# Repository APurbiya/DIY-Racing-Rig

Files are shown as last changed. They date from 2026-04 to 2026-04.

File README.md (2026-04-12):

 

<p align="center">
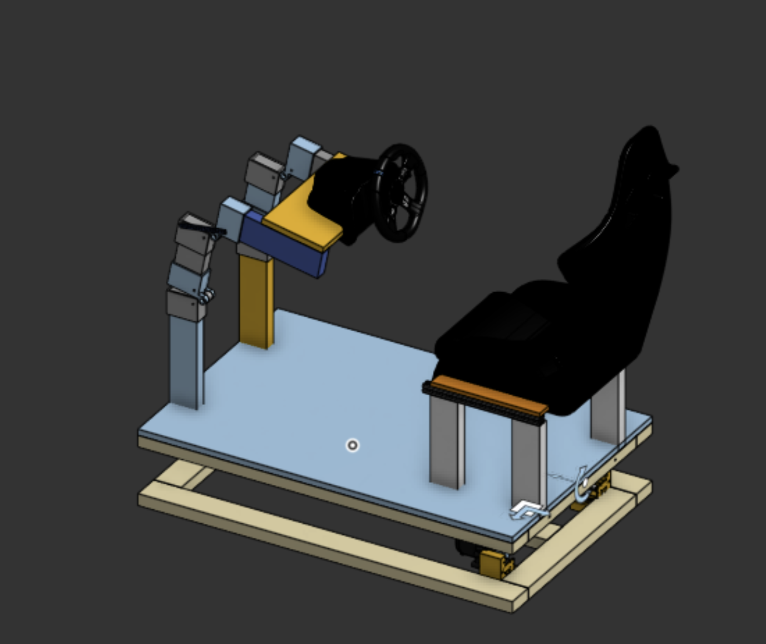
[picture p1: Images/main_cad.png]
DIY-Racing-Rig
  
</p>

# DIY-Racing-Rig
An open-source, 2-Degree-of-Freedom (2DOF) motion racing simulator designed for high immersion and DIY accessibility. This project utilizes a robust timber frame, high-torque DC gear motors, and magnetic encoders to translate in-game telemetry into real-time physical pitch and roll.

We wanted to make this project as it gives us not only experience in building a cool project, but also lets us have fun with the project, by playing on it once it is done. 

By Arnav Purbiya and Sai Avula

# Table of Contents

- [System Overview](#system-overview)
- [CAD](#cad)
- [3D Printing Guide](#3d-printing-guide)
- [Assembly Guide](#assembly-guide)
- [Electronics](#electronics)
- [Firmware](#firmware)
- [BOM](#bom)

# System Overview

The DIY-Racing-Rig is a motion-actuated platform designed to bridge the gap between virtual racing and physical reality. By translating in-game telemetry into physical movement, the rig simulates the G-forces, weight shifts, and road textures experienced during high-performance driving.

### How It Works
The system operates as a **2-Degree-of-Freedom (2DOF)** motion platform, focusing on the two most critical axes for racing immersion:
* **Pitch:** Simulates the longitudinal forces of acceleration (leaning back) and braking (leaning forward).
* **Roll:** Simulates the lateral forces of cornering and weight transfer through turns.

### Mechanical Architecture
* **The Fulcrum:** A heavy-duty, 3D-printed **Universal Joint (U-Joint)** serves as the mechanical heart of the rig. It supports the full weight of the upper chassis and driver while allowing for fluid movement across both axes.
* **Actuation:** High-torque 24V 250W geared DC motors drive the platform via a physical linkage system. These motors are capable of rapid transitions to mimic sudden weight shifts or bumps in the road.

### Electronic Control & Feedback
To ensure precision and eliminate "drift," the rig utilizes a **Closed-Loop Feedback System**:
1.  **Telemetry Data:** Software (SimTools) extracts live physics data from the game and sends it to an **Arduino Uno R3**.
2.  **Logic:** The Arduino calculates the required position for each motor.
3.  **Position Sensing:** **AS5600 Magnetic Encoders** mounted to the motors provide real-time angular feedback, allowing the Arduino to verify the rig's exact orientation.
4.  **Power Delivery:** High-current **BTS7960 Motor Drivers** translate the logic signals into raw power, moving the motors to the target position with high torque and low latency.

### Design Goals
* **Accessibility:** Built primarily from standard 2x4 timber and 3D-printed components to keep costs low.
* **Durability:** Strategic use of PETG in high-stress areas (U-Joint and Control Arms) ensures long-term structural integrity.
* **Immersive Precision:** The combination of 250W motors and magnetic encoders provides a snappy, responsive experience that reacts instantly to in-game events.

# CAD
You can find the cad on onshape, link down bellow
https://cad.onshape.com/documents/b552f3261af86a9135d49db9/w/8cfbd36bcd7ad18b09077ea0/e/34b6498e013fb992d3270d66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

## 3D Printing Guide

For structural components like the U-Joint and Center, **PETG** is preferred for its impact resistance and durability. If substituting with **PLA**, ensure the part is kept away from high-heat environments.

| Part Name | Qty | Material (Rec.) | Infill / Settings | Notes |
| :--- | :---: | :--- | :--- | :--- |
| **Hinge P1** | 4 | PLA | Default | Standard settings. |
| **Hinge P2** | 4 | PLA | Default | Standard settings. |
| **Hinge Strap** | 4 | PLA | Default | Standard settings. |
| **U-Joint Top** | 1 | PETG | 50% | High stress; PLA acceptable at 50%. |
| **U-Joint Bottom** | 1 | PETG | 50% | High stress; PLA acceptable at 50%. |
| **U Joint Center** | 1 | PETG | 50% (4 Walls) | Structural core; use 4 wall loops. |
| **Motor Mounts** | 2 | PLA | 20% | Standard settings. |
| **Motor Control Arms**| 2 | PETG | 80% Gyroid | Use Gyroid infill for maximum rigidity. |

---

## Assembly Guide

### Phase 1: The Cut List
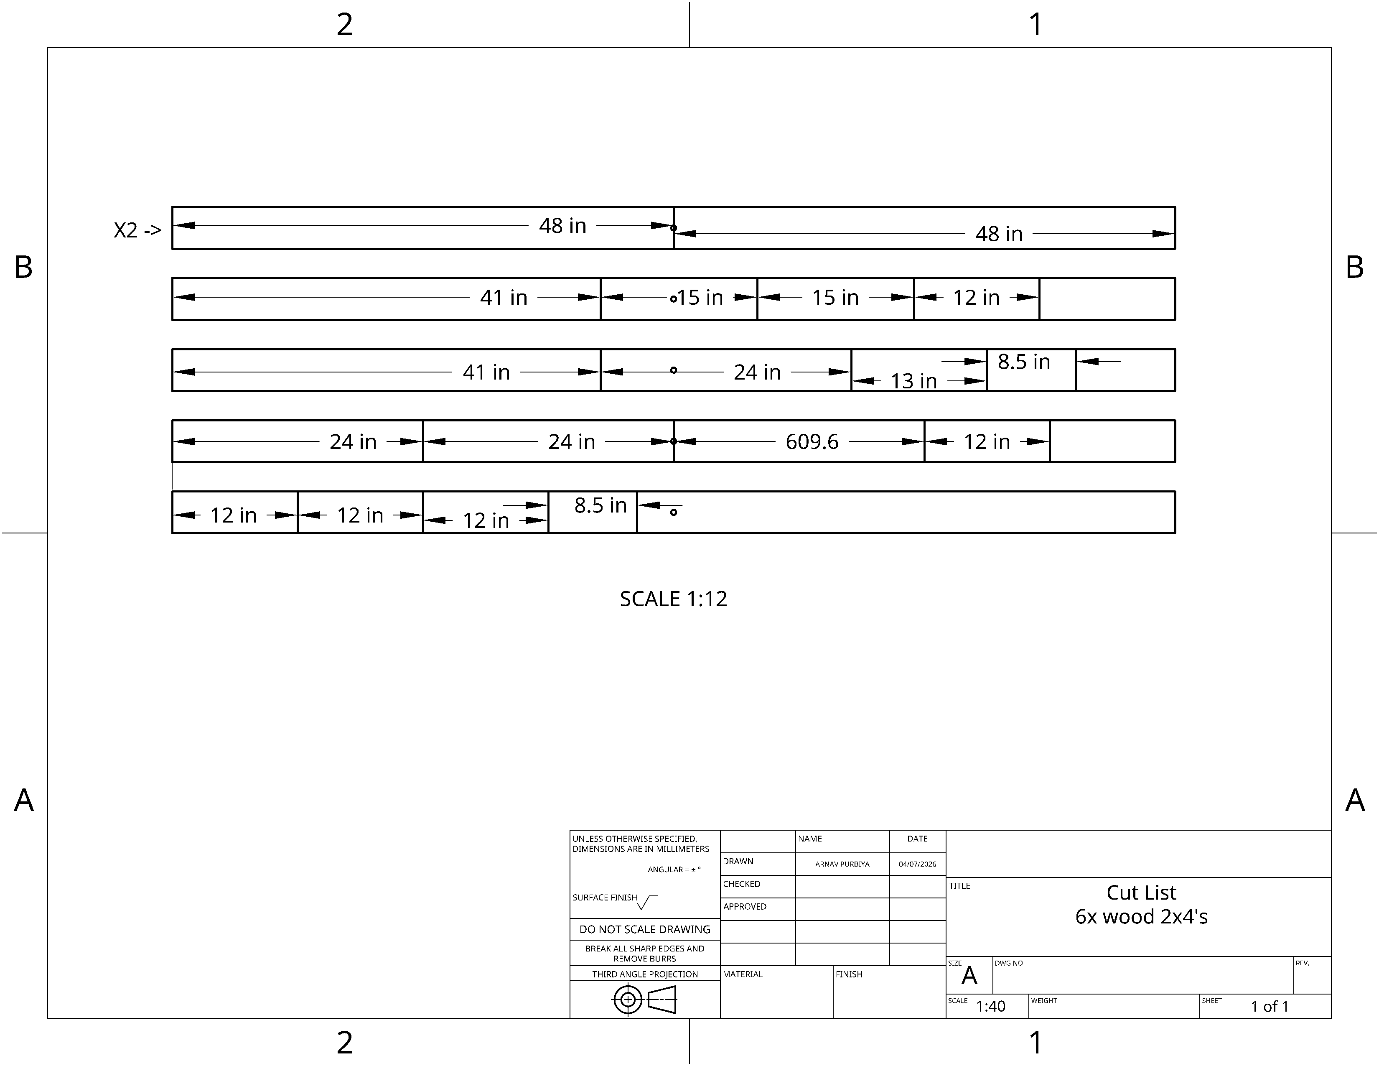
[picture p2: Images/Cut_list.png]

Before beginning assembly, reference the `cut_list.png` diagram. 
* **Stock:** Use (6) standard 8-foot 2x4s.
* **Precision:** The cut list accounts for the saw blade kerf. 
* **Scrap:** Expect a small amount of leftover material at the end of each board.

### Phase 2: Building the Dual Bases
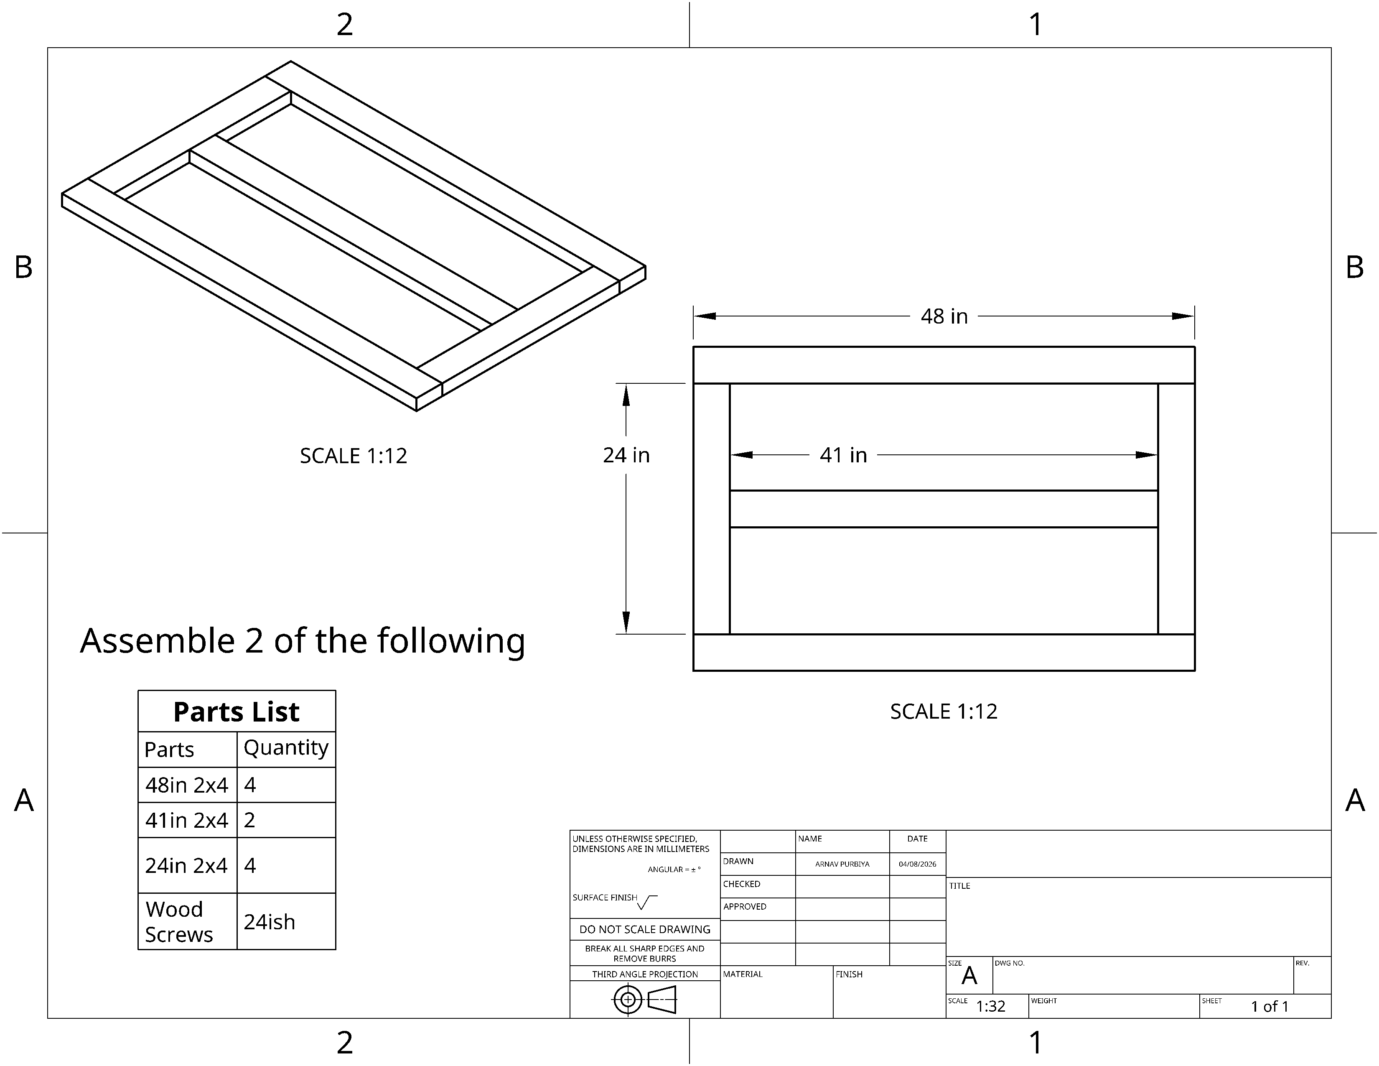
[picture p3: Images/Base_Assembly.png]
Base Assembly

You will need to construct **two identical base units** following the `base_assembly` guide. 
1. Lay out the 2x4 segments as indicated in the assembly diagram.
2. Fasten the joints using wood screws or heavy-duty lag bolts. 
3. **Note:** One base will serve as the ground foundation, while the second will serve as the top platform mounted to the U-Joint.

### Phase 3: The U-Joint & Center Hub
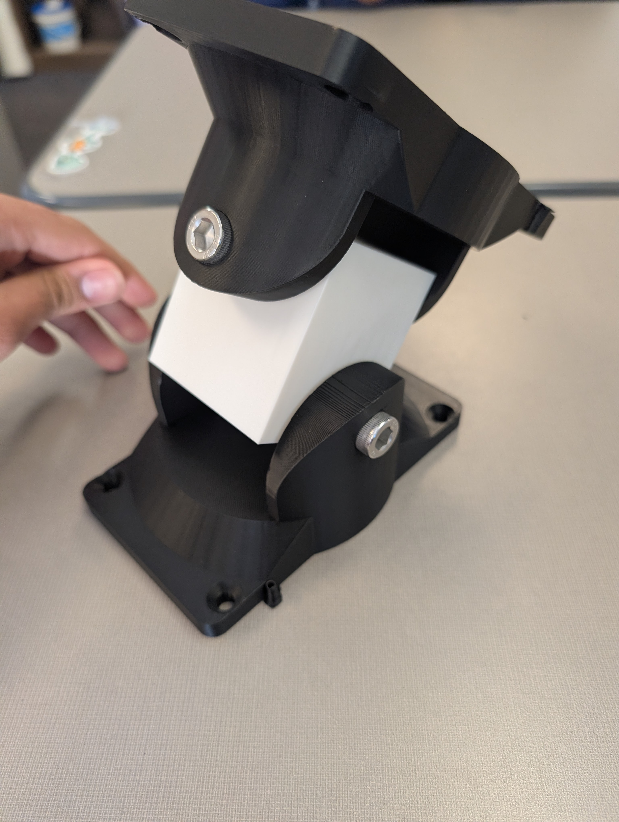
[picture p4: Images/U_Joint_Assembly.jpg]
U_Joint_Assembly

This is the mechanical heart of the build. The U joint is put together with 4 M10 Bolts and Lock Nuts 
1. **Lower Mount:** Attach the **U-Joint Bottom** to the center of the ground base. 
2. **Center Integration:** Insert the **Center Hub** into the U-Joint assembly.
3. **Upper Mount:** Attach the **U-Joint Top** to the 41-inch center 2x4 of the second (top) base.
4. **Final Marriage:** Join the top base assembly to the bottom base assembly via the U-Joint. Ensure all mechanical pivots move freely before tightening fasteners.

### Phase 4: Steering Wheel Stand Assembly
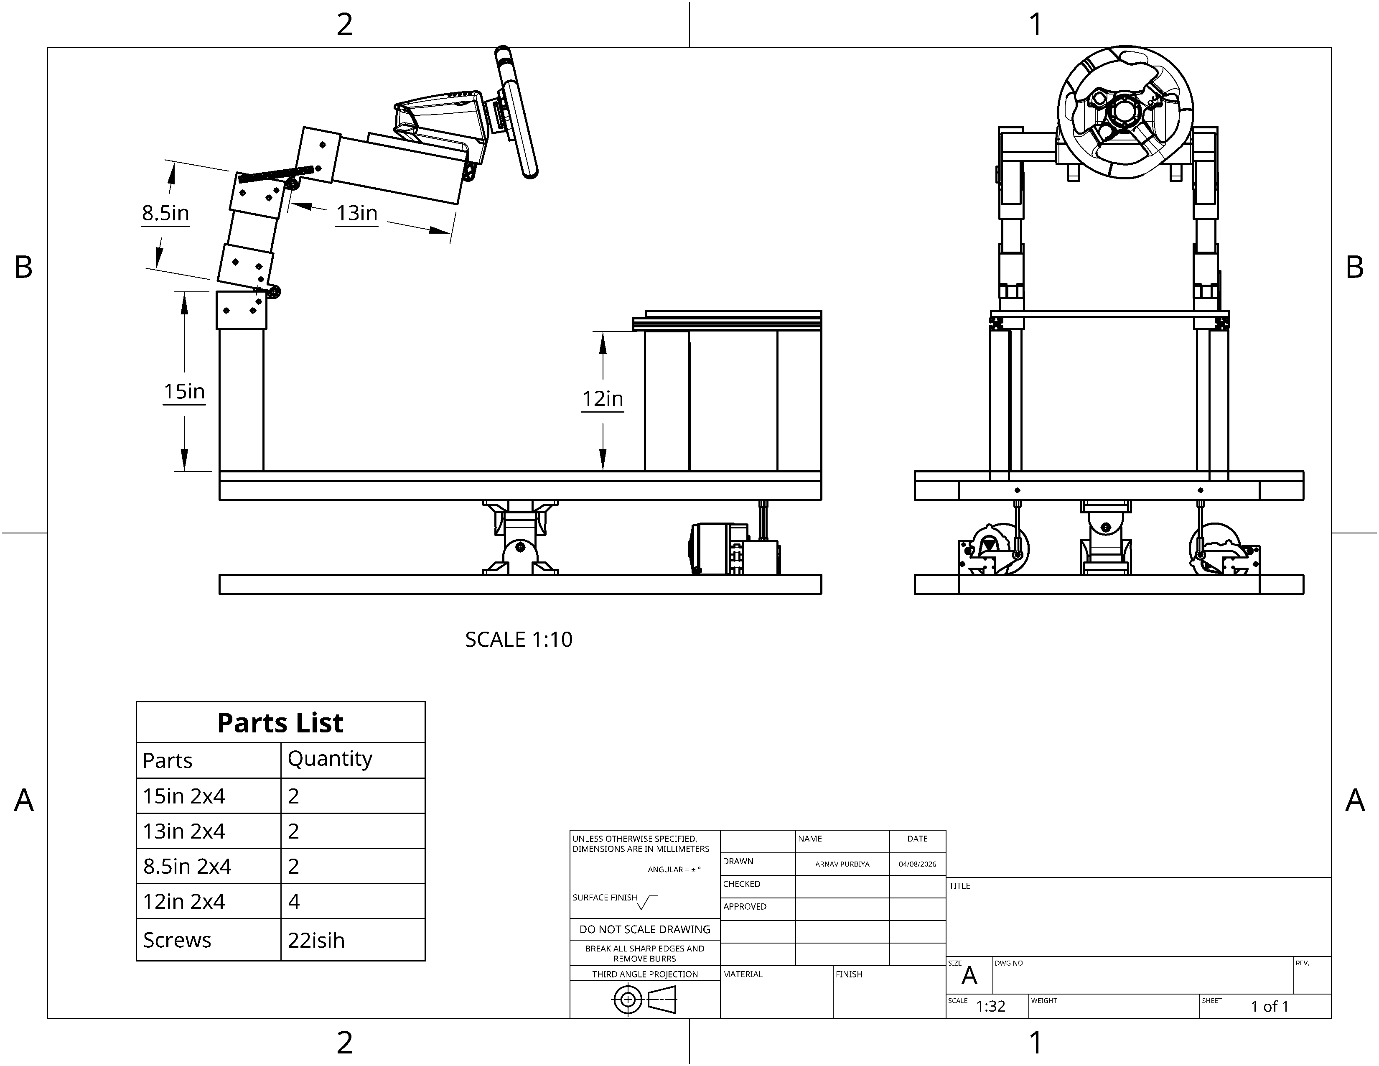
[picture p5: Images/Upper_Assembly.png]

The steering wheel stand is a hinged vertical assembly. Reference the `upper_assembly` diagram for specific orientation.
1. **Hinge Preparation:** Connect **Hinge 1** and **Hinge 2** using an **M10 bolt and nut**. Ensure the hinge is snug but allows for smooth rotation.
2. **Wood Sequence:** Mount the 2x4 segments to the hinges using wood screws. The assembly order from top to bottom is:
    * **15-inch segment** (Top)
    * **8.5-inch segment** (Middle)
    * **13-inch segment** (Bottom)
3. **Orientation:** When mounting, ensure the **hinge pivot point faces the inside** of the assembly to allow for proper folding/adjustment.

### Phase 5: Seat Stand Installation
The seat stand is adjustable based on your specific seating hardware.
1. **Placement:** Take the (4) **12-inch 2x4 segments**.
2. **Mounting:** Screw these into the bottom base assembly. 
3. **Spacing:** Adjust the distance between these segments to match the mounting rails or holes of your specific seat before final fastening.

### Phase 6: Motors and Linkage
1. **Actuation:** Install the **Motor Mounts** to the designated points on the frame. 
2. **Linkage:** Connect the **Motor Control Arms** between the motors and the moving frame. These arms provide the mechanical leverage for the motion system.
3. This is all done with the threaded rods and the bearing rod ends
---

## Electronics
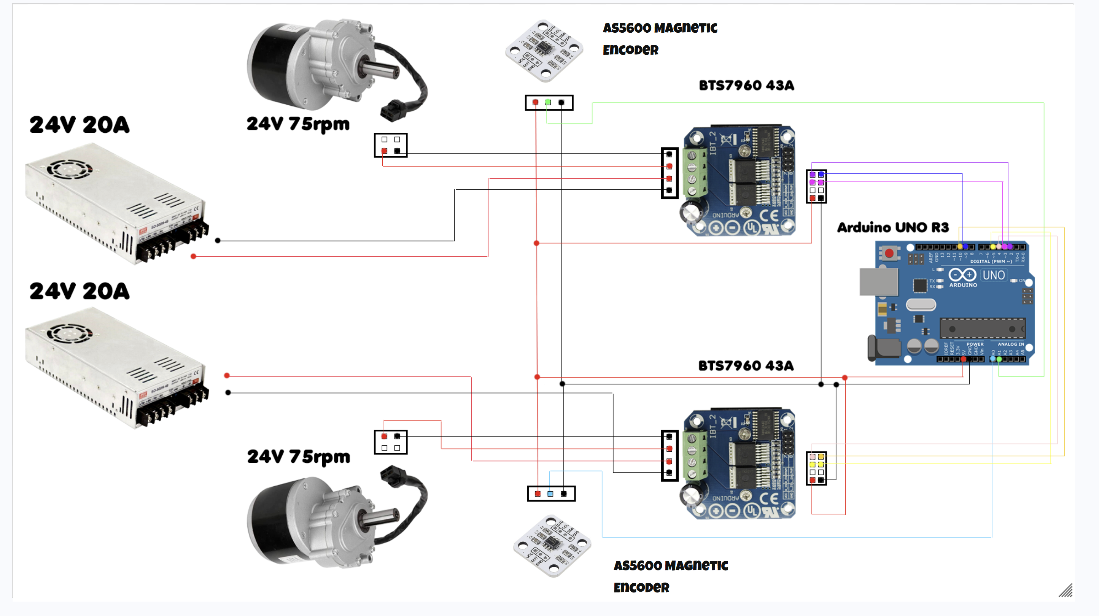
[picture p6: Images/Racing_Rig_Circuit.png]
Wiring Diagram


#### Connect the 2 motor controllers to the Arduino uno R3, connect each power supply to its individual motor controller, and connect each AS5600 Magnetic Encoder to the Arduino Uno analog pins, power the Arduino uno with a laptop which also communicates over serial for movement. The motor with the encoder creats a closed loop system which helps track movement exactly.  
---

## Firmware

This is the motor controller firmware for the 2DOF racing rig, running on an Arduino UNO R3. It controls two 24V 75rpm motors via BTS7960 43A H-bridge drivers using a PID control loop, taking position feedback from AS5600 magnetic encoders on each axis.

### How It Works

The Arduino runs a 4kHz control loop that continuously reads the position of both motors, compares them to the target positions being sent from the PC, and adjusts the motor power accordingly using PID math. The faster and more accurately it can do this, the smoother the motion feels.

### Serial Commands

Connect via Serial Monitor at **500000 baud**. All commands use the format `[xxx]`.

| Command | Description |
|---|---|
| `[h]` | Print full command list |
| `[d]` | Run diagnostics |
| `[Axxx]` | Set left motor target (0-1023) |
| `[Bxxx]` | Set right motor target (0-1023) |
| `[ena]` | Enable both motors |
| `[en1]` / `[en2]` | Enable left / right motor individually |
| `[sav]` | Save all settings to EEPROM |
| `[ver]` | Print firmware version |
| `[mo1]` / `[mo2]` / `[mo0]` | Start / stop live telemetry |

### Pin Assignments

| Pin | Function |
|---|---|
| 9 | Left motor PWM |
| 10 | Right motor PWM |
| 2 / 3 | Left H-bridge ENA / ENB |
| 4 / 5 | Right H-bridge ENA / ENB |
| A0 | Left encoder feedback |
| A1 | Right encoder feedback |

### Safety Features

If the Arduino stops receiving commands from the PC for more than 15 seconds, it automatically reduces motor power as a precaution. Motors also instantly cut if the encoder reads outside the safe range, and on every power cycle both axes slowly center themselves before the PID takes over.

## BOM 
|Name |Purpose |Quantity |Total Cost (USD) |Link |Distributor |
|---|---|---|---|---|---|
|Wood screws 2.75in |To attach all the wood|1 |12.98 |https://www.homedepot.com/p/Everbilt-10-x-2-3-4-in-Brown-6-Lobe-Torx-Drive-Exterior-Flat-Head-Multi-Material-Screw-1-lbs-Box-69-Piece-115317/331301660 |Home Depot |
|1/4-20 lock nuts |nuts for screws |1 |3.95 |https://www.amazon.com/WEGOUP-Stainless-Insert-Self-Locking-Coarse/dp/B0DJGTG4YM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|Amazon |
|1/4-20 x2in Screw |Screws for the hinge|1 |5.99 |https://www.amazon.com/Machine-Phillips-Stainless-Bright-Finish/dp/B0CXD12HPQ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|Amazon |
|2x4 Wood |Structure |6 |17.88 |https://www.homedepot.com/p/2-in-x-4-in-x-96-in-2-Premium-Grade-KD-HT-Stud-058449/312528776 |Home Depot |
|Motor Controler (Pack of 2) |Control motor with Arduino|1 |21.98 |https://www.amazon.com/HiLetgo-BTS7960-Driver-Arduino-Current/dp/B00WSN98DC?th=1 |Amazon |
|PSU |Supply power to motors|2 |42.76 |https://www.amazon.com/Taormey-Converter-Switching-Universal-Transformer/dp/B0DP988CNG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|Amazon |
|Motor |Movement |2 |104.20 |https://www.walmart.com/ip/24V-250W-Brushed-Gear-Electric-Motor-MY1016Z-Brushed-DC-Motor-75rpm-for-Electric-Wheelchair-Beach-Carts-Sport-Recreation-Other/18392363920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|Walmart |
|AS5600 Magnetic Encoder |To track movements|1 |8.99 |https://www.amazon.com/AOICRIE-Magnetic-Precision-Induction-Measurement/dp/B09SD7RHXS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|Amazon |

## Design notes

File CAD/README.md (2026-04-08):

Link to onshape assembly  https://cad.onshape.com/documents/b552f3261af86a9135d49db9/w/8cfbd36bcd7ad18b09077ea0/e/34b6498e013fb992d3270d66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

Main_CAD assembly

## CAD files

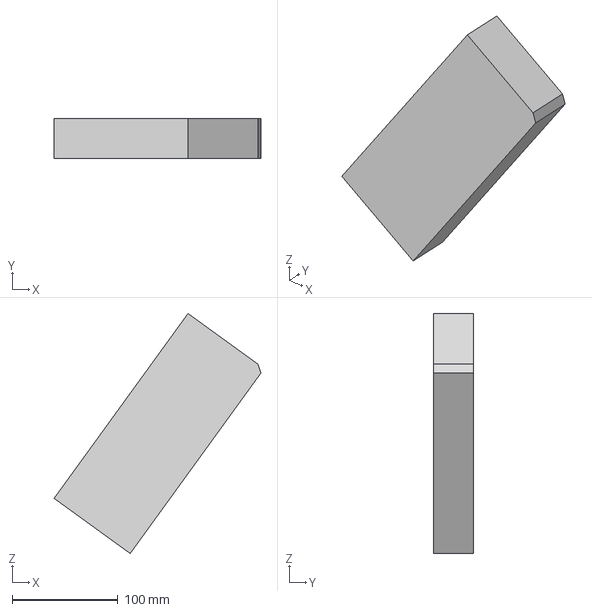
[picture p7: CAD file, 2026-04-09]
CAD/Main_Assembly_Parts/Main_Assembly 2 - 8.5in.step
195.6 x 38.1 x 227.0 mm

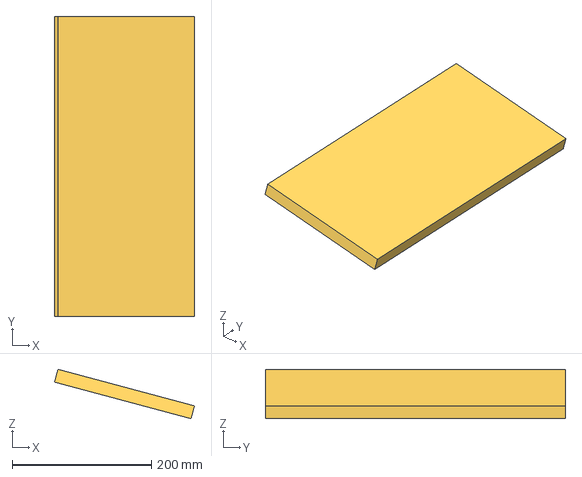
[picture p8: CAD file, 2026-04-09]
CAD/Main_Assembly_Parts/Main_Assembly 2 - Part 22.step
201.2 x 431.8 x 71.0 mm

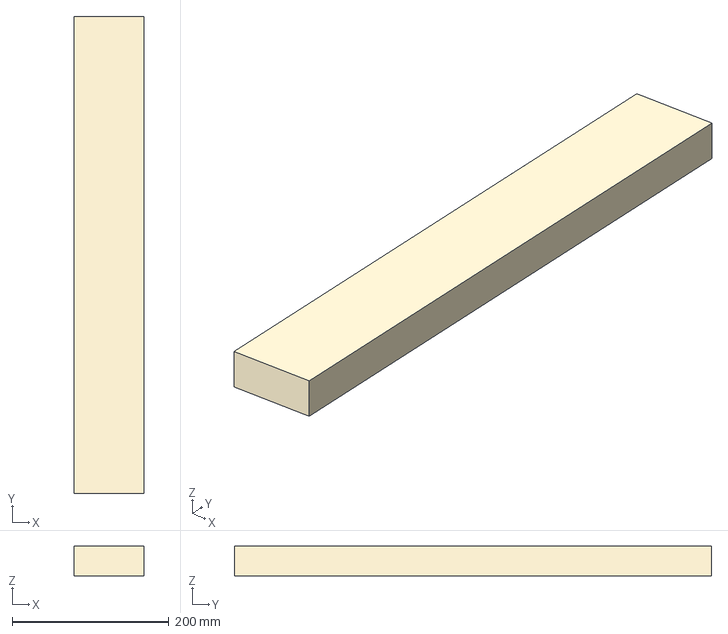
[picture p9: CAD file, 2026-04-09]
CAD/Main_Assembly_Parts/Main_Assembly 2 - 24in.step
88.9 x 609.6 x 38.1 mm

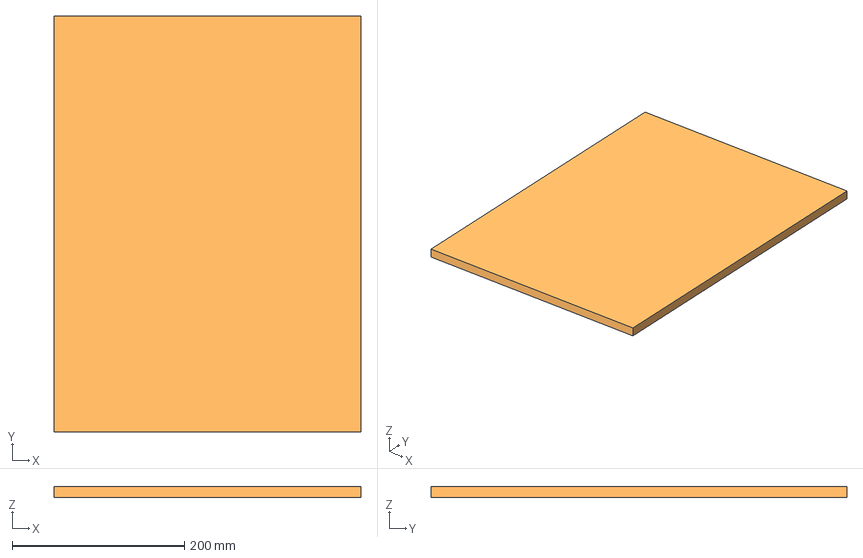
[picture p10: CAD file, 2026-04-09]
CAD/Main_Assembly_Parts/Main_Assembly 2 - Part 21.step
355.6 x 482.6 x 12.7 mm

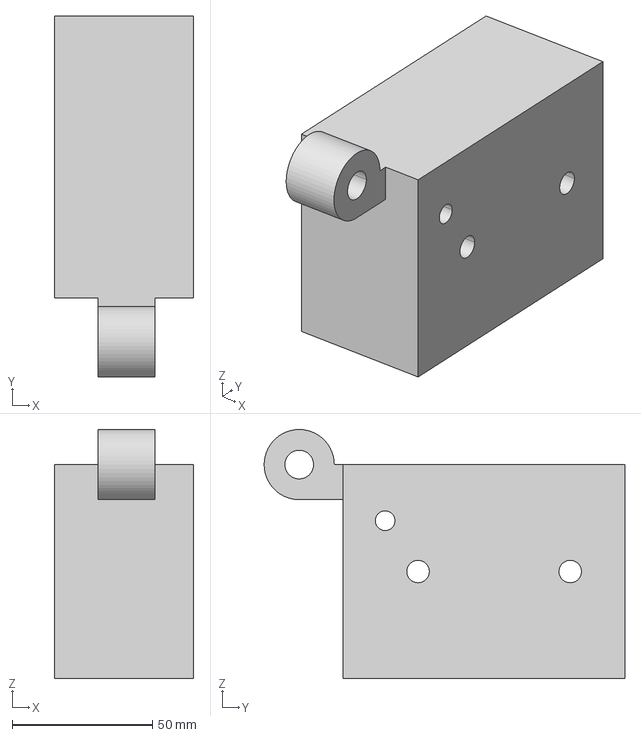
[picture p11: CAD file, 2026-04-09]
CAD/Main_Assembly_Parts/Main_Assembly 2 - Hinge_P2.step
49.6 x 128.5 x 88.7 mm

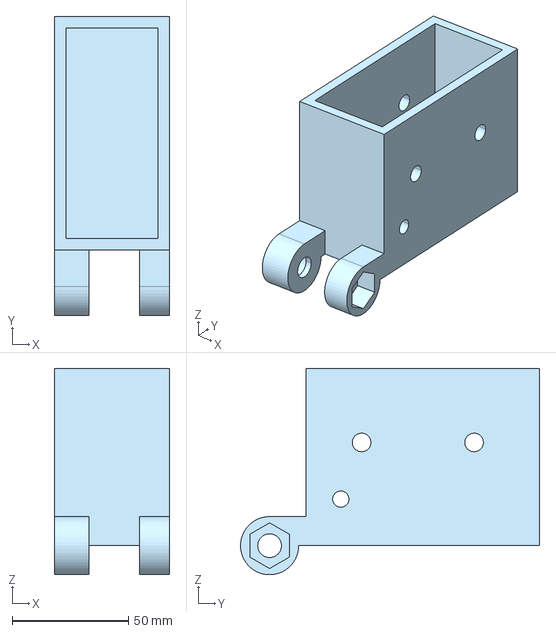
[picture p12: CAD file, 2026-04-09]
CAD/Main_Assembly_Parts/Main_Assembly 2 - Hinge_P1.step
49.6 x 128.5 x 88.6 mm

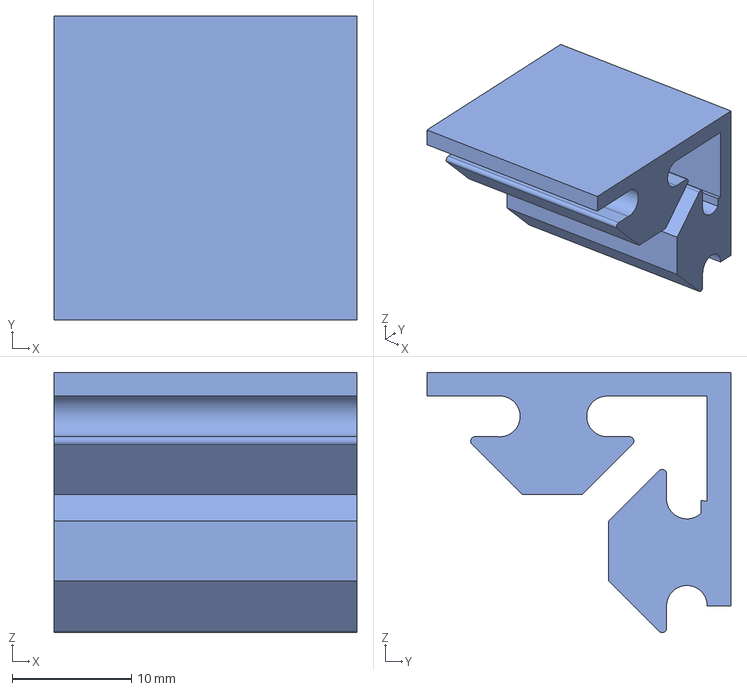
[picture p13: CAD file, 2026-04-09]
CAD/Main_Assembly_Parts/Main_Assembly 2 - Part 25.step
25.4 x 25.5 x 21.8 mm

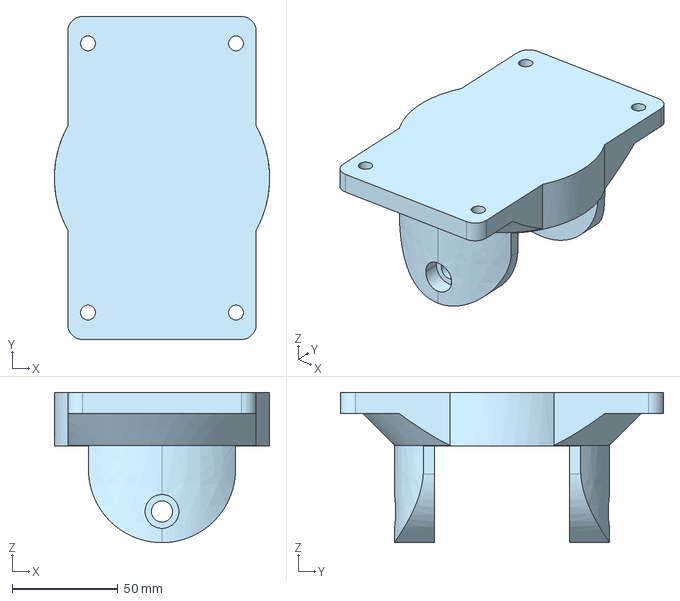
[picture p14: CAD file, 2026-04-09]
CAD/Main_Assembly_Parts/Main_Assembly 2 - Top.step
101.6 x 152.4 x 70.9 mm

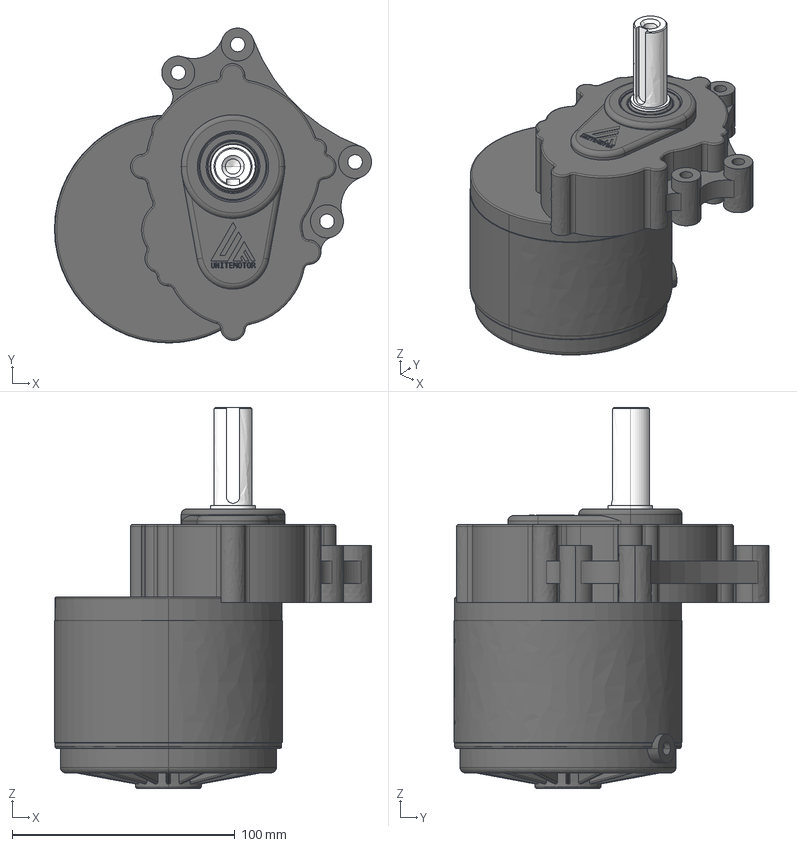
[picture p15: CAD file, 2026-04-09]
CAD/Main_Assembly_Parts/Main_Assembly 2 - ZD101AZ1-250W24V.step
142.3 x 141.3 x 171.0 mm

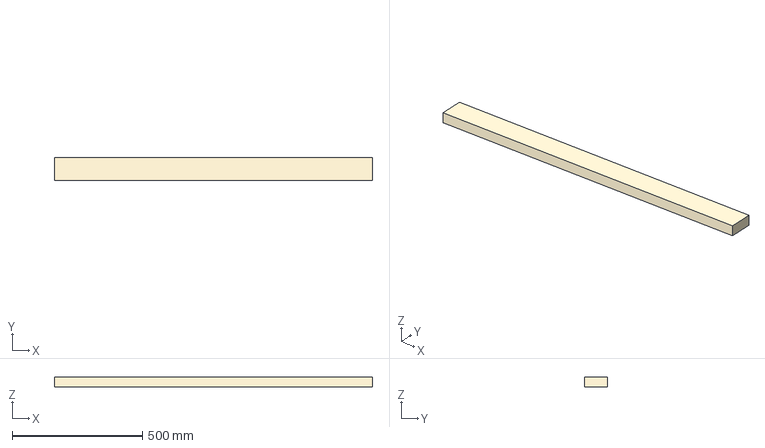
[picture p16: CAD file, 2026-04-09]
CAD/Main_Assembly_Parts/Main_Assembly 2 - 48in.step
1219.2 x 88.9 x 38.1 mm

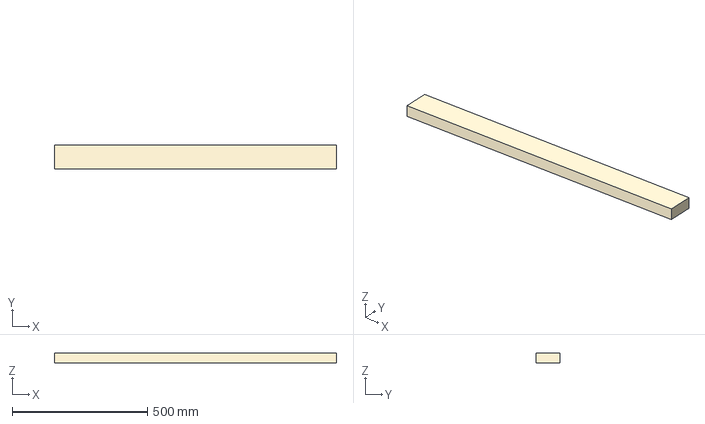
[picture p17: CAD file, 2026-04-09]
CAD/Main_Assembly_Parts/Main_Assembly 2 - 41in.step
1041.4 x 88.9 x 38.1 mm

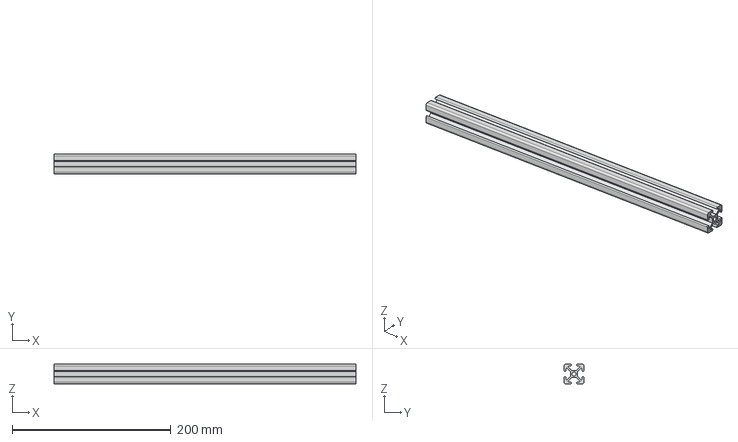
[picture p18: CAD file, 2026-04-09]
CAD/Main_Assembly_Parts/Main_Assembly 2 - Part 24.step
381.0 x 25.0 x 25.0 mm

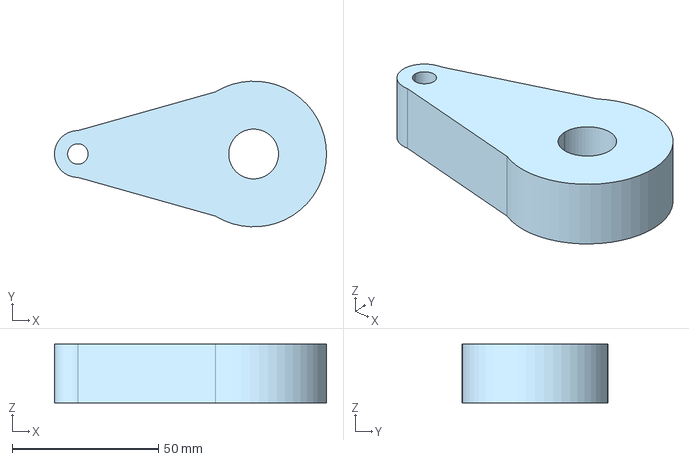
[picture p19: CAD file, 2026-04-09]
CAD/Main_Assembly_Parts/Main_Assembly 2 - Control Arm.step
92.9 x 49.7 x 20.0 mm

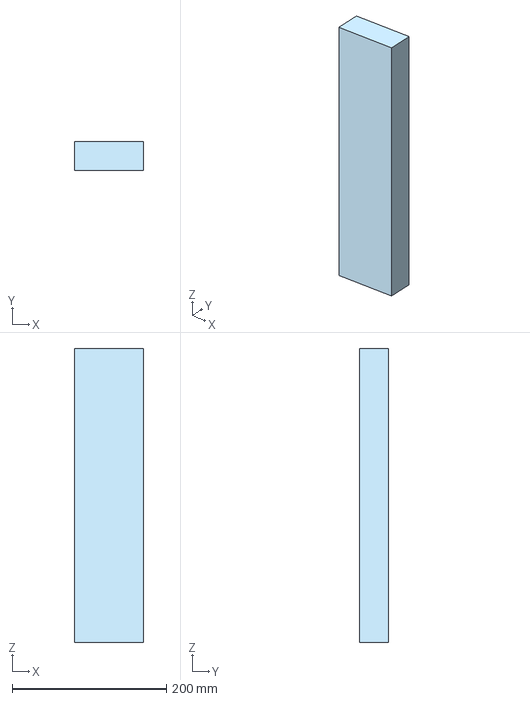
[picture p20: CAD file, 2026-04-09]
CAD/Main_Assembly_Parts/Main_Assembly 2 - 15in.step
88.9 x 38.1 x 381.0 mm

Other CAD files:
CAD/Main_Assembly_Parts/Main_Assembly 2 - Bottom.step
CAD/Main_Assembly_Parts/Main_Assembly 2 - Rod End Bearing.step
CAD/Main_Assembly_Parts/Main_Assembly 2 - Threaded Rod.step
CAD/Main_Assembly_Parts/Main_Assembly 2 - 12in.step
CAD/3d_print/Hinge - Hinge_P1.stl
CAD/3d_print/Hinge - Hinge_P2.stl
CAD/3d_print/Hinge - Strap.stl
CAD/3d_print/U-Joint - Bottom.stl
CAD/3d_print/U-Joint - Center.stl
CAD/3d_print/U-Joint - Top.stl
CAD/3d_print/ZD101AZ1-250W24V - Control Arm.stl
CAD/3d_print/ZD101AZ1-250W24V - Motor_Mount.stl
CAD/Main_Assembly_Parts/Main_Assembly 2 - 12in (1).step
CAD/Main_Assembly_Parts/Main_Assembly 2 - 12in (2).step
CAD/Main_Assembly_Parts/Main_Assembly 2 - 12in (3).step
CAD/Main_Assembly_Parts/Main_Assembly 2 - 13in (1).step
CAD/Main_Assembly_Parts/Main_Assembly 2 - 13in.step
CAD/Main_Assembly_Parts/Main_Assembly 2 - 15in (1).step
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

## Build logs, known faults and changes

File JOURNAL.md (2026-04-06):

<!--
  This journal is auto generated by Stasis.
-->

# 4/5/2026 11 PM - Electronics + CAD + Software

_Time spent: 6.833333333333333h_

We started by getting on call and while I was working on some cad Sai started doing research on when software we could use to control everything. For cad I had to make a rail system to move the seat as we were unsucssesfull in finding a seat yesterday, I have 2 8020 aluminum rails at home so we plan on using those as the base, I sketched thoes in and added them to the assembly





I also changed the screws used in the hinge design from 1/4-20 to M10s as we need all the strength we can get. I also made the extrude to allow and head and the nut to sit inside instead of sticking out 



In the mean time Sai did research and cam accros a bunch of tools "SimHub, Sim Racing Studio (SRS), SimTools, and FlyPT Mover" But only SM3C seemed to be something we could modify to use for our case. Then I remembered that we forgot to make a mount for the sensor, so while I made some other cad changes Sai did some research to see if the AS5600 Magnetic Encoder could be used with the uno and if it would work with our software, and if we would need a logic shifter. Once we confriemed we did not need a logic sensor I cadded the mount for the sensor.




I might have to make an adaptor to fit the magnet or we might just find a way to epoxy it into the motor hole and make sure it works. 

Here are some of the sources to Sai's research
https://www.instructables.com/AS5600-Magnetic-Angle-Encoder/

https://38-3d.co.uk/blogs/blog/how-to-use-the-as5600-magnetic-rotary-encoder-with-arduino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





Both of us for on google meet for almost 4 hours figuring out some of the smalled cad details and software and sensors, but we did take 10-15 mins breaks so I won't log that.









# 4/4/2026 6 PM - CAD + Junkyard + Goodwill

_Time spent: 5.25h_

I started the day of by doing some cad, I replaced the temp control arms with the threaded rod, I could not find the parts on grab cad so I designed it based on the amazon listing







That took me about an hour to do in the morning, then Me and Sai when to the junk yard, we found 2 good seats, and tried taking one of them out after spending an hour trying to take one of those out and it not coming out cause the bolts were rusted and the heads were striped, we tried on a different car, still no luck after another hour :( , we were both working for almost 2 hours from either side trying to get it out with no luck.

Then we drove down to goodwill to see if they had a office chair no luck there but we ended up spending about 10-15 mins in there.

**I am not counting the time it took us to drive around in the journal. we just ended up wasting a bunch of time trying to get a seat out.**



PXL_20260404_165059049.MP

PXL_20260404_182201770.MP

PXL_20260404_164804097.MP















# 4/4/2026 12 AM - Motor Mount + Motion CAD

_Time spent: 2.5h_

I started by making the mounts for the motor and sketchig around some of its complex geometry, I then made a rough control horn and rod to see if the motion would work, I also make a temp control rod, when building the thing I am going to be using threaded rots and Rod End Bearing I am going to be added thoese to the stasis bom soon, I also tried to see what angles I would need for everything to work which is when onshape got really slow cause of the time lapse, so I turned it off and did about an hour more of cad to get the angels the way I want them and adjust the motor mount a little, I left the seat the way it is but me and my friend are going to go to the salvage yard tomorrow to get the seat we need and then we can cad everything based on that.





My friend did not do any work this journal, all the work was done by me, so no double hours.




# 4/3/2026 4 AM - Tesing the size IRL

_Time spent: 4.25h_

okay we started by measuring the stuff irl we took a projector and projected the sketch on a wall, and scalled it my using a referance mesurement, and zooming in or out very slowly to get the mesurments just where we wanted it. This way we were able to see the seating and how the wheel would feel in our hands and how we would sit. We were working and my friend Sai's house from 5:30 - 7:00 just getting everything just the way we wanted it, although getting the cad and projector to scale with the a tape measure was the hardest part.



Once we got all of that I went home and made some of the remaing changes of some of the mates and the small stuff, I also added screws and nuts to the bom that the hinge will needed, and added 1 more 2x4 as we has to increase some of the lengths by a bit. 

We also are going to try to get a real car sear out of a junked car with all the rail system and the reline features, so we don't have to worry about that too much.

Then after eating dinner I spent some time trying to figure out how to mount the motor so I can get the best motion, I decided to mount it somewhere like that so the red part can be the like a servo horn and the blue part is like a linking rod.


Next I need to make the mounts for the motor and make the linkage rods and test that movement, while I do that Sai will most likely start working on the code and figuring out firmware and how to control the motors and and stuff





# 4/2/2026 9 PM - More cad + drawing + thinking

_Time spent: 4.5h_

Lot of CAD work done, 



While I worked on the imports of the seat, wheel and the motor







While I was importing stuff and adding booleans to join stuff together, Sai was working on a hinge design to get the angels for the steering wheel, we are plannign on using 1/4-20 screws to make the hinge work,  We need to angel stuff correctly, but we have the sketch almost done,

We are going to project the sketch on a wall and scale and it, to see if it fits us right. 





Out of the 2 hours of time lapse 1h 30min we both were working together so 3 hours the other 30 mins I was working on my own, and then we both worked individually for 30 mins as well seperatly at our own time.








# 4/2/2026 3 AM - CAD + Mesurments

_Time spent: 7h_

This next session had a lot more visible progress, in terms of cad we started by taking measurments of te stand Sai has and then we started making those changes in cad, I also made some more progress on the pivot point which will take the load of the whole project,




But before we started extruding stuff we spent a bunch of time reseaching what we should use to build the whole thing, we first thought of using the 8020 aluminum extrusion but we realized that would very easily be more than 150$ so that would be out of budget, So we decided to use 2x4s and make the whole thing out of wood, and 3d print,cut gussets as needed. Thats how we started cadding all the parts to be out of 2x4, we first extruded everything 2inx4in but then remembered its actually 1.5x3.5 so we had to go back and change all the dimentions this is when I made a variable studio to do all this, 

**I also tried using the timelapse feature but it was taking up to much cpu and ram slowing everything so I did not record it for the whole time of my half of this session**

The session breakdown:
Me and sai both spent time researching if aluminum could be used and seeing the cost, then did cad then had to go back and fix all dimentions, I worked on the pivot and took IRL measurments to try and make everything as best to scale as we could.








# 4/1/2026 9 PM - Research + CAD

_Time spent: 6.5h_

I started by working on the cad, converting our drawing into a ought sketch that we can then extrude different parts of the make the entire stucture. While I was doing this my friend Sai worked on researching which parts we could use, how powerfull the motors need to be. He found this page with a video that is kinda similar to what we want to do but not exactly what we want to do.
https://www.sckgaming.es/tutorial-2dof-motion/

While he was doing that I was looking up how big everything needs to be and how everything with roughtly come together, which is when I found 

I am going to use almost the same dimentions as these, I made the onshape document https://cad.onshape.com/documents/b552f3261af86a9135d49db9/w/8cfbd36bcd7ad18b09077ea0/e/1c3c927a8e100f80d34581d2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

and then started the work this is what the rought sketch looks like, 



I also worked on the CAD for the U-Joint as we wern't able to find one that we can buy for cheap.



While I was working on cad, my friend did research first thinking of using stepper motors with 10:1 gear boxes but that would be wayyy to expensive so he decided to used just normal geard 75 rpm motors with a rotory encoder for position. We most parts he was able to make a BOM, version 1 is with the stepper motors and version 2 is the one looking more promising. 








# 4/1/2026 4 AM - Idea + Rough Sketch

_Time spent: 1.416666666666667h_

Me and my friend are working on this project together, first we talked about the what this project should be able to do.
1. We need it to be able to connect with the play station
2. Give atleast 2 asix of motion, so banking left/right and front/back for breaking/accelerating

For this reason we were thinking of doing one pivot point we 2 motors kinda like servos with arms that allow the structure on top to be moved. We drew out our idea and started looking for how we would make the pivot work. When researching we found a U-joint which allows for the type of motion we are looking for, while being a low profile, we drew the side and front view of what we kinda want it too look like. The whole thing is going to work with the wheel and foot pedals he already has.



Next we are going to start making the sketch into cad and making a BOM with all the parts.






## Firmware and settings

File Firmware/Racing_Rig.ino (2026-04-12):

//****************************************************************************************************************
// Racing_Rig.ino - Ultra-High Performance 2-Motor PID Motion Controller
// Developed for: H-Bridge Motor Drivers (BTS7960 / IBT-2 Compatible)
// Protocol: SMC3 Compatible Serial Interface
//****************************************************************************************************************

#define MODE1    

#include <EEPROM.h>
#include <SoftwareSerial.h>

/* * MACRO DEFINITIONS 
 * These handle register-level bit manipulation to bypass slow Arduino functions.
 * sbi = Set Bit / cbi = Clear Bit
 */
#ifndef cbi
    #define cbi(sfr, bit) (_SFR_BYTE(sfr) &= ~_BV(bit))
#endif
#ifndef sbi
    #define sbi(sfr, bit) (_SFR_BYTE(sfr) |= _BV(bit))
#endif

// --- System Constants ---
#define COM0 0                          
#define START_BYTE '['       
#define END_BYTE ']'                    
#define PROCESS_PERIOD_uS 250   // 4kHz Control Loop Frequency

// --- Global Timing Control ---
unsigned long NextProcessTime = 0;
unsigned long CurrentTime = 0;
unsigned long LoopCounter = 0;
unsigned long DiagnosticTimer = 0;

// --- High-Precision PID State Variables ---
// We use long to maintain precision during complex mathematical multiplications
long Error_Left, LastError_Left, Iterm_Left;
long Error_Right, LastError_Right, Iterm_Right;

// --- Motor Feedback and Target positions ---
int Feedback_Left = 512;
int Feedback_Right = 512;
int Target_Left = 512;
int Target_Right = 512;
int PotInput = 512;

// --- Serial Communication Buffers ---
unsigned int RxByte[1] = {0};
int RxPtr[1] = {-1};
unsigned int RxBuffer[5][1] = {0};

// --- Hardware Pin Assignments ---
// Motors are assigned to Timer1 (Pins 9/10) for 25kHz Ultrasonic PWM
const int ENApin_Left = 2;
const int ENBpin_Left = 3;
const int ENApin_Right = 4;
const int ENBpin_Right = 5;
const int PWMpin_Left = 9;
const int PWMpin_Right = 10;
const int FeedbackPin_Left = A0;
const int FeedbackPin_Right = A1;

// --- Mechanical Calibration Variables ---
int DeadZone_Left = 0;
int DeadZone_Right = 0;
int CutoffLimitMax_Left = 1000;
int CutoffLimitMax_Right = 1000;
int CutoffLimitMin_Left = 23;
int CutoffLimitMin_Right = 23;
int InputClipMax_Left = 923;
int InputClipMax_Right = 923;
int InputClipMin_Left = 100;
int InputClipMin_Right = 100;

// --- PID Control Tuning ---
long Kp_Left_x100 = 100;
long Ki_Left_x100 = 40;
long Kd_Left_x100 = 40;
int Ks_Left = 1;

long Kp_Right_x100 = 420;
long Ki_Right_x100 = 40;
long Kd_Right_x100 = 40;
int Ks_Right = 1;

// --- PWM Power Constraints ---
int PWMout_Left = 0;
int PWMout_Right = 0;
int PWMoffset_Left = 50;
int PWMoffset_Right = 50;
int PWMmax_Left = 100;
int PWMmax_Right = 100;
int PWMrev_Left = 200;
int PWMrev_Right = 200;

// --- Operational State Flags ---
int Disable_Left = 1;
int Disable_Right = 1;
unsigned int Timer1FreqkHz = 25; 

// --- Timer1 Configuration (25kHz PWM) ---
void InitialisePWMTimer1(unsigned int Freq) 
{
    // Fast PWM mode with ICR1 as TOP value
    uint8_t wgm = 8;
    TCCR1A = (TCCR1A & B11111100) | (wgm & B00000011);
    TCCR1B = (TCCR1B & B11100111) | ((wgm & B00001100) << 1);
    TCCR1B = (TCCR1B & B11111000) | 0x01; 
    ICR1 = (F_CPU / 2) / Freq;
}

// Optimized PWM Write using direct register access
void MyPWMWrite(uint8_t pin, uint8_t val) 
{
    #define OCR1A_MEM 0x88
    #define OCR1B_MEM 0x8A
    pinMode(pin, OUTPUT);
    uint32_t tmp = val;
    
    if (val == 0) 
    {
        digitalWrite(pin, LOW);
    } 
    else if (val == 255) {
        digitalWrite(pin, HIGH);
    } 
    else 
    {
        uint16_t regLoc16 = (pin == 9) ? OCR1A_MEM : OCR1B_MEM;
        if (pin == 9) 
        {
            sbi(TCCR1A, COM1A1);
        } 
        else 
        {
            sbi(TCCR1A, COM1B1);
        }
        tmp = (tmp * ICR1) / 255;
        _SFR_MEM16(regLoc16) = tmp;
    }
}

// --- EEPROM Handlers ---
void WriteEEPRomWord(int address, int intvalue) 
{
    EEPROM.write(address, intvalue / 256);
    EEPROM.write(address + 1, intvalue % 256);
}

int ReadEEPRomWord(int address) 
{
    return (EEPROM.read(address) * 256) + EEPROM.read(address + 1);
}

// --- Save Rig Calibration ---
void WriteEEProm() 
{
    EEPROM.write(0, 114); 
    EEPROM.write(1, CutoffLimitMin_Left);
    EEPROM.write(2, InputClipMin_Left);
    EEPROM.write(3, CutoffLimitMin_Right); 
    EEPROM.write(4, InputClipMin_Right);
    EEPROM.write(5, DeadZone_Left);
    EEPROM.write(6, DeadZone_Right);
    
    WriteEEPRomWord(11, Kp_Left_x100);
    WriteEEPRomWord(13, Ki_Left_x100);
    WriteEEPRomWord(15, Kd_Left_x100);
    EEPROM.write(23, PWMoffset_Left);
    EEPROM.write(25, PWMmax_Left);
    EEPROM.write(27, PWMrev_Left);
    
    WriteEEPRomWord(31, Kp_Right_x100);
    WriteEEPRomWord(33, Ki_Right_x100);
    WriteEEPRomWord(35, Kd_Right_x100);
    EEPROM.write(43, PWMoffset_Right);
    EEPROM.write(45, PWMmax_Right);
    EEPROM.write(47, PWMrev_Right);
}

// --- Load Rig Calibration ---
void ReadEEProm() 
{
    if(EEPROM.read(0) != 114) 
    { 
        WriteEEProm(); 
        return; 
    }
    CutoffLimitMin_Left = EEPROM.read(1);
    InputClipMin_Left = EEPROM.read(2);
    CutoffLimitMin_Right = EEPROM.read(3);
    InputClipMin_Right = EEPROM.read(4);
    
    CutoffLimitMax_Left = 1023 - CutoffLimitMin_Left;
    InputClipMax_Left = 1023 - InputClipMin_Left;
    CutoffLimitMax_Right = 1023 - CutoffLimitMin_Right;
    InputClipMax_Right = 1023 - InputClipMin_Right;

    Kp_Left_x100 = ReadEEPRomWord(11);
    Ki_Left_x100 = ReadEEPRomWord(13);
    Kd_Left_x100 = ReadEEPRomWord(15);
    Kp_Right_x100 = ReadEEPRomWord(31);
}

// --- PID Math Engine: Motor 1 ---
void CalculatePID_Left() 
{
    if (Disable_Left) return;
    Error_Left = Target_Left - Feedback_Left;
    
    if (abs(Error_Left) <= DeadZone_Left) 
    {
        PWMout_Left = 0;
    } 
    else 
    {
        long pTerm = (Kp_Left_x100 * Error_Left) / 100;
        Iterm_Left += (Ki_Left_x100 * Error_Left) / 100;
        
        // Integral Anti-Windup
        if (Iterm_Left > 12000) 
        {
            Iterm_Left = 12000;
        }
        else if (Iterm_Left < -12000) 
        {
            Iterm_Left = -12000;
        }
        
        long dTerm = (Kd_Left_x100 * (Error_Left - LastError_Left)) / 100;
        LastError_Left = Error_Left;
        
        PWMout_Left = (pTerm + (Iterm_Left / 10) + dTerm) / Ks_Left;
    }
    DriveMotorLeft(PWMout_Left);
}

// --- PID Math Engine: Motor 2 ---
void CalculatePID_Right() 
{
    if (Disable_Right) return;
    Error_Right = Target_Right - Feedback_Right;
    
    if (abs(Error_Right) <= DeadZone_Right) 
    {
        PWMout_Right = 0;
    } 
    else 
    {
        long pTerm = (Kp_Right_x100 * Error_Right) / 100;
        Iterm_Right += (Ki_Right_x100 * Error_Right) / 100;
        
        if (Iterm_Right > 12000) 
        {
            Iterm_Right = 12000;
        }
        else if (Iterm_Right < -12000) 
        {
            Iterm_Right = -12000;
        }
        
        long dTerm = (Kd_Right_x100 * (Error_Right - LastError_Right)) / 100;
        LastError_Right = Error_Right;
        
        PWMout_Right = (pTerm + (Iterm_Right / 10) + dTerm) / Ks_Right;
    }
    DriveMotorRight(PWMout_Right);
}

// --- Motor Direction Control ---
void DriveMotorLeft(int power) 
{
    int out = abs(power) + PWMoffset_Left;
    if (out > PWMmax_Left) out = PWMmax_Left;

    if (power > 0) 
    {
        digitalWrite(ENApin_Left, HIGH); 
        digitalWrite(ENBpin_Left, LOW);
        MyPWMWrite(PWMpin_Left, out);
    } 
    else if (power < 0) 
    {
        digitalWrite(ENApin_Left, LOW); 
        digitalWrite(ENBpin_Left, HIGH);
        MyPWMWrite(PWMpin_Left, out);
    } 
    else 
    {
        digitalWrite(ENApin_Left, LOW); 
        digitalWrite(ENBpin_Left, LOW);
        MyPWMWrite(PWMpin_Left, PWMrev_Left);
    }
}

void DriveMotorRight(int power) 
{
    int out = abs(power) + PWMoffset_Right;
    if (out > PWMmax_Right) 
    {
        out = PWMmax_Right;
    }

    if (power > 0) 
    {
        digitalWrite(ENApin_Right, HIGH); 
        digitalWrite(ENBpin_Right, LOW);
        MyPWMWrite(PWMpin_Right, out);
    } 
    else if (power < 0) 
    {
        digitalWrite(ENApin_Right, LOW); 
        digitalWrite(ENBpin_Right, HIGH);
        MyPWMWrite(PWMpin_Right, out);
    } 
    else 
    {
        digitalWrite(ENApin_Right, LOW); 
        digitalWrite(ENBpin_Right, LOW);
        MyPWMWrite(PWMpin_Right, PWMrev_Right);
    }
}

// --- Serial Command Parser ---
void ParseCommand(int ComPort) 
{
    switch (RxBuffer[0][ComPort]) 
    {
        case 'A': 
            Target_Left = (RxBuffer[1][ComPort] * 256) + RxBuffer[2][ComPort];
            Target_Left = constrain(Target_Left, InputClipMin_Left, InputClipMax_Left);
            Disable_Left = 0;
            break;
        case 'B': 
            Target_Right = (RxBuffer[1][ComPort] * 256) + RxBuffer[2][ComPort];
            Target_Right = constrain(Target_Right, InputClipMin_Right, InputClipMax_Right);
            Disable_Right = 0;
            break;
        case 'S': 
            WriteEEProm();
            break;
        case 'h':
            PrintHelpMenu(); 
            break;
        case 'd':
            RunRigDiagnostics(); 
            break;
    }
}

void PrintHelpMenu() 
{
    Serial.println(F("\n--- RIG MAINTENANCE COMMANDS ---"));
    Serial.println(F(" [Axxx] - Move Left Axis (0-1023)"));
    Serial.println(F(" [Bxxx] - Move Right Axis (0-1023)"));
    Serial.println(F(" [S]    - Save Current Calibration to EEPROM"));
    Serial.println(F(" [h]    - Show this Help Menu"));
    Serial.println(F(" [d]    - Run System Diagnostics"));
    Serial.println(F("---------------------------------"));
}

// --- Safety Interlocks ---
void DisableMotorLeft() 
{ 
    Disable_Left = 1; 
    digitalWrite(2, LOW); 
    digitalWrite(3, LOW); 
    MyPWMWrite(9, 0); 
}
void DisableMotorRight() 
{ 
    Disable_Right = 1; 
    digitalWrite(4, LOW); 
    digitalWrite(5, LOW); 
    MyPWMWrite(10, 0); 
}

// --- Hardware Initialization ---
void setup() 
{
    ReadEEProm();
    Serial.begin(500000);
    
    pinMode(ENApin_Left, OUTPUT); 
    pinMode(ENBpin_Left, OUTPUT);
    pinMode(ENApin_Right, OUTPUT); 
    pinMode(ENBpin_Right, OUTPUT);
    
    InitialisePWMTimer1(Timer1FreqkHz * 1000);
    
    // speed up ADC sampling
    sbi(ADCSRA, ADPS2); 
    cbi(ADCSRA, ADPS1); 
    cbi(ADCSRA, ADPS0); 
    
    DisableMotorLeft(); 
    DisableMotorRight();
    Serial.println(F("SYSTEM_ONLINE_STABLE"));
}

// --- Main Control Loop ---
void loop() 
{
    // Serial Data Processing
    while (Serial.available() > 0) 
    {
        RxByte[COM0] = Serial.read();
        if (RxByte[COM0] == START_BYTE) 
        {
            RxPtr[COM0] = 0;
        }
        else if (RxPtr[COM0] >= 0) 
        {
            if (RxByte[COM0] == END_BYTE) 
            { 
                ParseCommand(COM0); RxPtr[COM0] = -1; 
            }
            else if (RxPtr[COM0] < 5) 
            { 
                RxBuffer[RxPtr[COM0]][COM0] = RxByte[COM0]; RxPtr[COM0]++; 
            }
        }
    }

   CurrentTime = micros();
    if (CurrentTime >= NextProcessTime) 
    {
        NextProcessTime = CurrentTime + PROCESS_PERIOD_uS;
        
        Feedback_Left = analogRead(FeedbackPin_Left);
        Feedback_Right = analogRead(FeedbackPin_Right);
        
        SmoothingModule_Left();
        SmoothingModule_Right();
        
        if (Feedback_Left > CutoffLimitMax_Left || Feedback_Left < CutoffLimitMin_Left) 
        {
            DisableMotorLeft();
        }
        
        if (Feedback_Right > CutoffLimitMax_Right || Feedback_Right < CutoffLimitMin_Right) 
        {
            DisableMotorRight();
        }
        
        CalculatePID_Left();
        CalculatePID_Right();
    }
}

void RunRigDiagnostics() 
{
    Serial.println(F("\n--- RACING RIG MASTER DIAGNOSTICS ---"));
    Serial.print(F("Firmware Version: ")); 
    Serial.println(F("4.0.0-STABLE"));
    Serial.print(F("Process Interval: ")); 
    Serial.print(PROCESS_PERIOD_uS); 
    Serial.println(F(" uS"));
    Serial.print(F("PWM Carrier Frequency: ")); 
    Serial.print(Timer1FreqkHz); 
    Serial.println(F(" kHz"));
    Serial.println(F("\n[AXIS A - LEFT MOTOR]"));
    Serial.print(F("  Feedback Raw: ")); 
    Serial.println(Feedback_Left);
    Serial.print(F("  Target Raw:   ")); 
    Serial.println(Target_Left);
    Serial.print(F("  PWM Output:   ")); 
    Serial.println(PWMout_Left);
    Serial.print(F("  Status:       ")); 
    if(Disable_Left) 
    { 
        Serial.println(F("OFFLINE (SAFETY)")); 
    }

    else             
    {
        Serial.println(F("ACTIVE")); 
    }
    
    Serial.println(F("\n[AXIS B - RIGHT MOTOR]"));
    Serial.print(F("  Feedback Raw: ")); 
    Serial.println(Feedback_Right);
    Serial.print(F("  Target Raw:   ")); 
    Serial.println(Target_Right);
    Serial.print(F("  PWM Output:   ")); 
    Serial.println(PWMout_Right);
    Serial.print(F("  Status:       ")); 
    if(Disable_Right) { Serial.println(F("OFFLINE (SAFETY)")); }
    else              { Serial.println(F("ACTIVE")); }
    Serial.println(F("--------------------------------------"));
}

void SmoothingModule_Left() 
{
    static int pFeedback_L = 512;
    Feedback_Left = (Feedback_Left + pFeedback_L) / 2;
    pFeedback_L = Feedback_Left;
}

void SmoothingModule_Right() 
{
    static int pFeedback_R = 512;
    Feedback_Right = (Feedback_Right + pFeedback_R) / 2;
    pFeedback_R = Feedback_Right;
}

void ManualCalibrationMode() 
{
    // Routine to center the rig before PID takes over
}

// --- End of original Racing_Rig code ---
// ========================================
// === DAY 2 ADDITIONS (~400 lines)
//     - Comms watchdog + PowerScale
//     - PID process divider
//     - Serial feedback auto-reporting
//     - SendValue / SendTwoValues
//     - DeltaLoopCount
//     - Full extended command parser
//     - Proper packet-level serial handler
// ========================================

// --- Comms watchdog state ---
unsigned int  CommsTimeout      = 0;   // Counts up each loop tick; reset on valid packet
byte          PowerScale        = 7;   // Right-shift applied to PID result (~divide by 128)
                                       // Set to 9 (~divide by 512) when comms lost
unsigned long LastLoopCount     = 0;
byte          errorcount        = 0;

// --- PID process divider ---
int PIDProcessDivider = 1;             // Run PID every N timer ticks
int PIDProcessCounter = 0;

// --- Serial feedback auto-reporting ---
int SerialFeedbackEnabled  = 0;        // 0=off, 1=left motor, 2=right motor
int SerialFeedbackCounter  = 0;

//****************************************************************************************************************
//  SendValue
//  Transmits a 16-bit integer as a 5-byte SMC3 protocol packet: [id][high][low]
//****************************************************************************************************************

void SendValue(int id, int value, int ComPort)
{
    int high = value / 256;
    int low  = value - (high * 256);
    Serial.write(START_BYTE);
    Serial.write(id);
    Serial.write(high);
    Serial.write(low);
    Serial.write(END_BYTE);
}

//****************************************************************************************************************
//  SendTwoValues
//  Transmits two 8-bit values in one SMC3 packet: [id][v1][v2]
//****************************************************************************************************************

void SendTwoValues(int id, int v1, int v2, int ComPort)
{
    Serial.write(START_BYTE);
    Serial.write(id);
    Serial.write(v1);
    Serial.write(v2);
    Serial.write(END_BYTE);
}

//****************************************************************************************************************
//  DeltaLoopCount
//  Returns the number of PID cycles completed since this function was last called.
//  Used by the host software to measure controller throughput.
//****************************************************************************************************************

int DeltaLoopCount()
{
    unsigned long delta;
    if ((LastLoopCount == 0) || ((LoopCounter - LastLoopCount) > 32000))
    {
        delta         = 0;
        LastLoopCount = LoopCounter;
    }
    else
    {
        delta         = LoopCounter - LastLoopCount;
        LastLoopCount = LoopCounter;
    }
    return (int)delta;
}

//****************************************************************************************************************
//  ParseCommand_Extended
//  Full SMC3-compatible command set. Handles all PID tuning parameters,
//  PWM limits, cutoff/clip limits, enable/disable, read-back requests,
//  serial monitor feedback control and firmware version reporting.
//  Delegates the original A/B/S/h/d cases to ParseCommand().
//****************************************************************************************************************
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

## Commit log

2026-04-08 Add README with Onshape assembly link and image
2026-04-09 Enhance Racing Rig firmware with PID updates
    Updated comments and added new PID control functions for improved performance and diagnostics.
2026-04-09 All 3d printed parts
    [Hinge - Hinge_P1.stl, Hinge - Hinge_P2.stl, Hinge - Strap.stl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]
2026-04-09 Add 3D printing guide to README
    Added a 3D printing guide with material recommendations and settings for various parts.
2026-04-09 All CAD files exported as step files
    [Main_Assembly 2 - 12in (1).step, Main_Assembly 2 - 12in (2).step, Main_Assembly 2 - 12in (3).step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]
2026-04-09 Main Assembly with everything mated
2026-04-09 Enhance README with 3D printing guide and author details
    Updated author names and added a 3D printing guide with material recommendations and assembly instructions.
2026-04-09 updated bom
    [Racing Rig BOM - Sheet1.csv]
2026-04-09 update bom, wiht quantity
2026-04-09 Add assembly diagrams to README
    Added images for cut list, base assembly, and upper assembly to the README.
2026-04-09 Add CAD section to README with onshape link
    Added CAD section with link to Onshape document.
2026-04-10 adding u joint addembly photo
2026-04-10 Enhance README with Table of Contents and details
    Added a Table of Contents and improved sections on assembly, electronics, and firmware.
2026-04-10 Fix table of contents links to be case-sensitive
2026-04-12 Refactor conditions and add calibration functions
    Refactor conditional statements for clarity and add new calibration and EEPROM functions.
2026-04-12 Update Code_ReadMe.md with firmware details
    Added detailed documentation for the Racing Rig firmware, including operational details, serial commands, pin assignments, and safety features.
2026-04-12 Update Motor Controller entry in BOM
    [Racing Rig BOM - Sheet1.csv]
2026-04-12 Update motor controller description and quantity
2026-04-12 Enhance README with firmware and operational details
    Expanded the firmware section with detailed explanations of how the motor controller works, including control loop frequency, serial commands, pin assignments, and safety features.
